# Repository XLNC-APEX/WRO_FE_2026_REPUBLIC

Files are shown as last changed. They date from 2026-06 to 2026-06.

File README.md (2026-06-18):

# 

 Welcome to the GitHub Repository of Team XLNC Apex from Kazakhstan, competing in the World Robot Olympiad Future Engineers 2026 category.

# Contents
- [The team](#the-team)
- [Challenge Overview](#challenge-overview)
- [Our Robot](#our-robot)
- [Mechanical systems](#mechanical-systems)
- [Electronic systems](#electronic-systems)
- [Software](#software)
- [Robot photos](#robot-photos)

## Directories structure
```shell
WRO_FE_2026_REGIONAL
├── code            # Our python code(uv project)
│   └── src         # Main code(open.py, obstacle.py)
│       └── tests   # Some code to test little things
├── images          # Images(for docs)
├── models          # Lego model, Pixy2 cam case
├── research        # Researches: obstacle, programming
├── t-photos        # Team photos
├── v-photos        # Vehicle Photos
└── README.md       # Main docs file
```

# The team

### Members

| Karabayev Darkhan | Abenov Sayan |
| --- | --- |
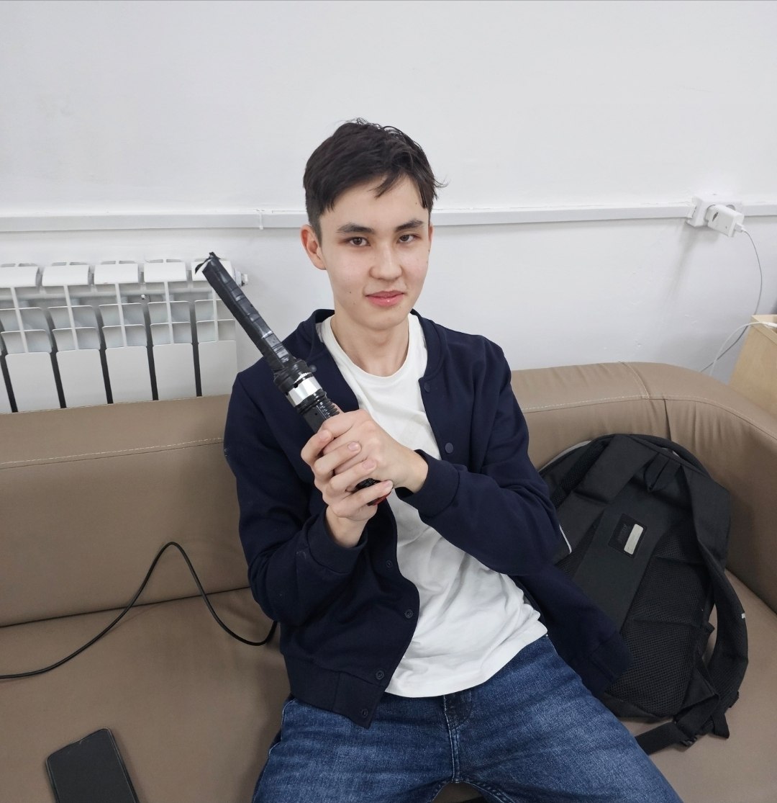
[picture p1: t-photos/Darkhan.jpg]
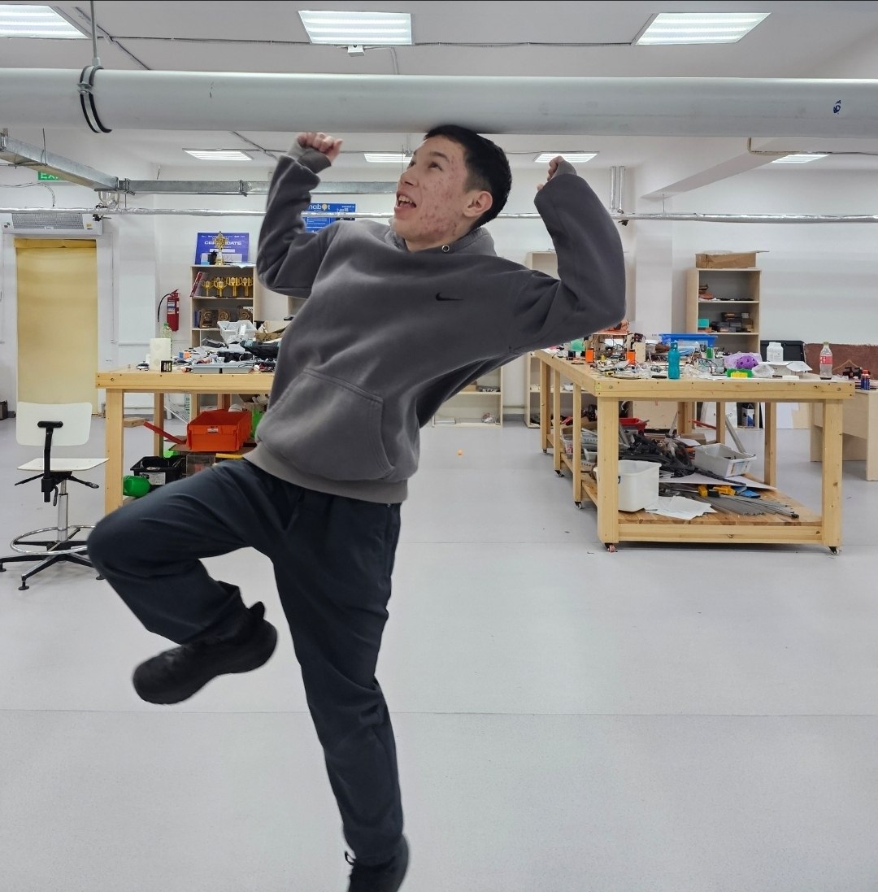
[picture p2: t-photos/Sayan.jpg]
|  |  |

# Challenge Overview

The **WRO Future Engineers** category requires building a **fully autonomous self-driving vehicle** that:

- Navigates a closed track without external control  
- Detects and avoids obstacles dynamically  
- Maintains stability and precision at speed  
- Adapts to uncertain and changing conditions  

Key engineering challenges:
- Real-time perception  
- Reducing sensor errors  
- Keeping right distance from walls  
- Reliability under competition constraints  

# System Architecture

Our robot is designed as a modular system consisting of three tightly integrated layers:

### 1. Perception Layer
- Vision-based detection using **Pixy2 camera**
- Object tracking and color signature recognition  
- Distance estimation using onboard sensors  

### 2. Control Layer
- Closed-loop control using **PID algorithms**  
- Steering and speed regulation  
- Real-time decision-making  

### 3. Execution Layer
- Motor actuation via LEGO EV3 platform  
- Precise movement and trajectory correction  

This layered approach allows us to isolate complexity and improve reliability.

# Our Robot

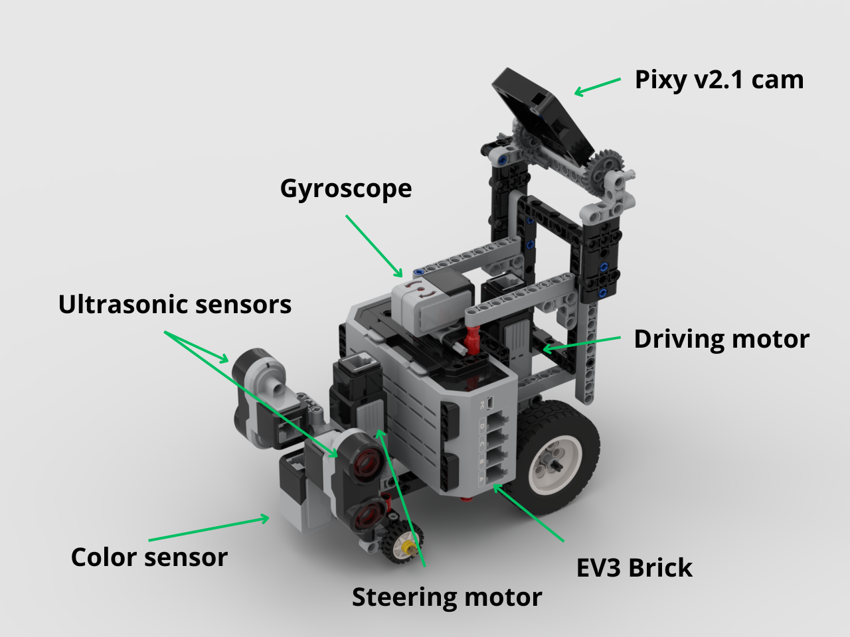
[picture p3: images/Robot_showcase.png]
Robot showcase


Our robot is a compact autonomous vehicle optimized for **speed, stability, and deterministic behavior**.

### Key Design Principles
- **Consistency over complexity**  
- **Low-latency decision making**  
- **Mechanical reliability first**  

### Capabilities
- Obstacle detection and avoidance  
- Smooth cornering with PID stabilization  
- Real-time trajectory correction  

# Mechanical Systems

The mechanical design is focused on achieving predictable and stable motion.

### Features
- Rigid and lightweight chassis  
- Optimized center of mass for high-speed turns  
- High-precision steering mechanism  
- Efficient drivetrain using LEGO components  

### Engineering Decisions
- Minimized mechanical play for better control accuracy  
- Balanced gear ratios for torque vs speed trade-off  
- Structural reinforcement for competition durability 

### Steering

### Geometry
We thought to use Ackerman's steering for more efficient turns. 
However, firstly we built this parallel steering.

incorrect_steering

Quickly noticed the issue and fixed it:

proper_steering

It works great, and since it meets our criteria, no Ackerman geometry is required.

| It is controlled by the medium ev3 motor. This motor has accurate encoder and after calibration at program start, it acts basically like a servo.| steering_motor |
| --- | --- |

### Rear-Wheel Drive(RWD)

We use differiential to properly drive while turning. It eliminates required otherwise wheels slippage, due to the fact that wheels travel arcs with different radii, thus, should rotate at different rates.
differential

It is powered by medium EV3 motor.

### Gyroscope

LEGO EV3 gyroscope is used to know robot orientation.

Problem: These gyroscopes drift frequently.

Reason: During gyroscope power on, it captures initial angular velocity. Also the error accumulates with time.

Solution: Power cycle the gyroscope. Pybricks added .calibrate() method to reboot ev3 gyro.

# Electronic Systems

Our robot is powered by the **LEGO EV3** platform with extended sensing capabilities.

### Core Components
- **LEGO EV3 Brick** — main controller  
- **Pixy2 Camera** — primary vision sensor  
- Motors with encoder feedback  
- Auxiliary sensors (distance, color, etc.)  

### Design Focus
- Reliable communication between modules  
- Low-latency sensor data processing  
- Stable power distribution  

When we started to prepare for WRO we had to choose the platform we are going to use.

We had a choice of completely custom platform or EV3 we already have.

Custom board requires us to choose components and order them, which can take up to a month of waiting. We have to design and 3d print parts.
Accounting for that, there probably at least a month to just assemble a first version of a robot. We wanted to start fast to spend more time programming.

The EV3 was the fastest to get started with.
EV3 robot assembly took approximately 1 day.(Later we added camera while programming).

[Assembly instructions for our robot are available.](xlnc_apex_instruction.pdf)

# Pixy 2.1 camera:

Photo of pixy 2.1 in our printed case on our robot

We had a part of the case, but not the front lid. That was an opportunity to learn FreeCAD and 3d printing! [Link to CAD](3d_models/pixy_holder/small_holder3.FCStd)

Pixy 2.1 front lid CAD

Camera is fixed on an axle and the viewing angle can be set using gears.

We set the optimal angle to fit as much field on screen and less noisy world

Camera view

# Software

The software stack is built using **Pybricks (MicroPython)** and follows a modular architecture.

### Core Modules
- **Steering Module**  
  - PD controller for gyroscope's angle
  - Tracking right steering angle 

- **Wall Avoidance Module**  
  - Finding the perpendicular to the outer wall
  - Proportional controller for distance from outer wall

- **Line Detection Module**  
  - Obstacle avoidance strategy  
  - State-based behavior system  

- **Obstacle Detection Module**  
  - Filtering unnecessary objects
  - The most optimal trajectory

### Coding platform:

After careful selection and [research](research/programming_environment_choice.md), for EV3, we chose an [experimental version of Pybricks](https://github.com/pybricks/pybricks-micropython/tree/master/bricks/ev3) with **significantly faster execution time** due to bare metal firmware and without the use of an SD card.

### Running the code

For uploading program to EV3 brick we use [pybricksdev](https://github.com/pybricks/pybricksdev). This package contains both command line tools and a library to call equivalent operations from within a Python script.

`pybricksdev` requires Python 3.10 or higher.

- For Windows, use the official Python installer or the Windows Store.
- For Mac, use the official Python installer or Homebrew (brew install python@3.12).
- For Linux, use the distro provided python3.12 or if not available, use a Python runtime version manager such as asdf or pyenv.

```shell
pybricksdev run usb code/src/open.py
```

### Pixy2 calibration

The Pixy2 camera is configured through the official PixyMon software. You need to connect the camera to your computer via the Micro-USB port to access the video and settings. By pressing and holding the white button, the camera enters teaching mode, and obstacle detection can be configured.

For more precise detection, signature ranges and camera brightness in settings need to be adjusted, and the Auto White Balance option should be switched off.

For more information, visit [Pixy Docs](https://docs.pixycam.com/wiki/doku.php?id=wiki:v2:teach_pixy_an_object_2).

### Open challenge:

For the open challenge, we chose a simple strategy of driving along the outer wall using a gyroscope and ultrasonic sensor. Turn and direction detection occur using a color sensor.

Firstly, the robot starts gyro calibration and angle resets. We reset the steering motor by running it until stalled to the left, to the right, and to the half. Then, a while loop starts until all 12 lines are passed. The car drives forward to the first line. The color sensor recognizes the color, whether it's orange or blue, and based on this, we can determine the direction (orange for clockwise and blue for counter-clockwise) and the right ultrasonic. Since the robot is driving along the outer wall, moving the internal walls won't bother the robot. The running loop operates at a > 50 Hz frequency; it's not much, but it's enough to successfully complete the task. We use a PD controller for the gyroscope and a proportional controller for wall detection. By reading the distance from the ultrasonic, we take into account the robot's rotation angle and find the perpendicular to the wall. To avoid reacting to the line twice per turn, we have a distance timeout, which is calculated using the rotation angle of the rear motor. Once the passed_lines variable is equal to 12 (which means all 3 laps are finished) the robot drives forward for a set period of time to land in its starting area and stops.

### Obstacle challenge:

The Obstacle Challenge is similar to the Open Challenge, with the exception of a Pixy2 camera correction as well as parking out.

#### Parking out
Robot is placed close to the farthest from moving direction parking wall. Then, the car determines the moving direction by the distance from side ultrasonic. 
The steering wheels rotate fully, car drives while turning, for approximately 800ms.

When the camera detects an obstacle, gyroscope and ultrasonic correction are disabled, and the robot follows the most optimal trajectory, which we've determined using point-based regression. As a result, the obstacle moves on the camera along an optimal nonlinear trajectory.

```python
#Code highlights
#code/src/ObstacleDetection.py
RED_CURVE = Curve2D(0.007155, -1.865848, 124.599494)
GREEN_CURVE = Curve2D(-0.007322, 1.880561, 187.050712)

#code/src/obstacle.py

obstacle_detection = ObstacleDetection(camera)

pixy_correction = obstacle_detection.get_correction()

steering.pid(pixy=pixy_correction, wall=wall_correction)
```

| **Green obstacle** | **Red obstacle** |
| --- | --- |
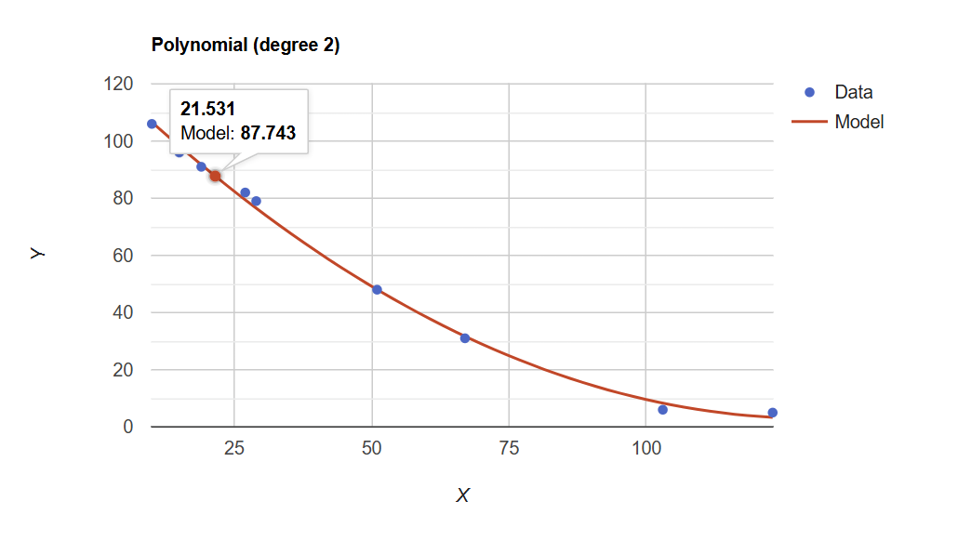
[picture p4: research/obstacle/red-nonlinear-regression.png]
Red obstacle trajectory
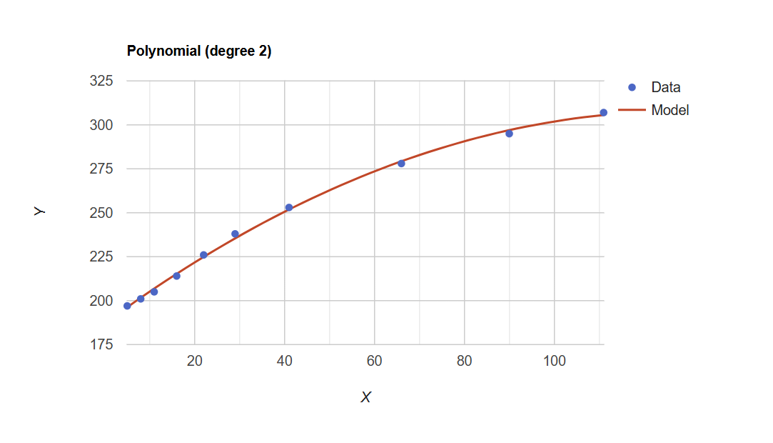
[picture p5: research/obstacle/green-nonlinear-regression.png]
Green obstacle trajectory
|  |  |

#### Obstacle filtering
Camera captures some out of field environment areas, as well as can be noisy and detect small blocks.

Filtering Blocks helps to reduce false positives. 

```python
#code/src/ObstacleDetection.py

def filter(block: Block) -> bool:
    if (block.height * block.width) > MIN_OBSTACLE_AREA:
        if crop_filter(block.x_center, block.y_center):
            return True
    return False

def crop_filter(x: int, y: int) -> bool:
    H_CROP = 10

    V_TOP_CROP = 35
    V_BOTTOM_CROP = 38
    if (x > H_CROP) and (x < (CAM_WIDTH - H_CROP)):
        if y > V_TOP_CROP:
            if y < (CAM_HEIGHT - V_BOTTOM_CROP):
                return True
    return False
```

We crop the view as well as discard too small blocks.

# Future plans & Problems

## Problems
 - Pixy2 is unstable, feature limited, power inefficient(heats up)

Plan: Try OpenMV H7 camera. It is programmable.

 - EV3 platform has limitations
    - low amount of ports
    - Limited programming ability
    - Big size and weight
    - Big slow motor

Plan: Build a robot with best available components like Pi Pico 2 microcontroller
([We already built it](https://github.com/XLNC-APEX/WRO_FE_2026_NATIONAL), but did not have time to program and document it)

 - Steering using EV3 medium motor requires finding extreme angles at initialization which takes ~ 1.5s

Plan: Use MG90S micro servo instead

# Robot photos

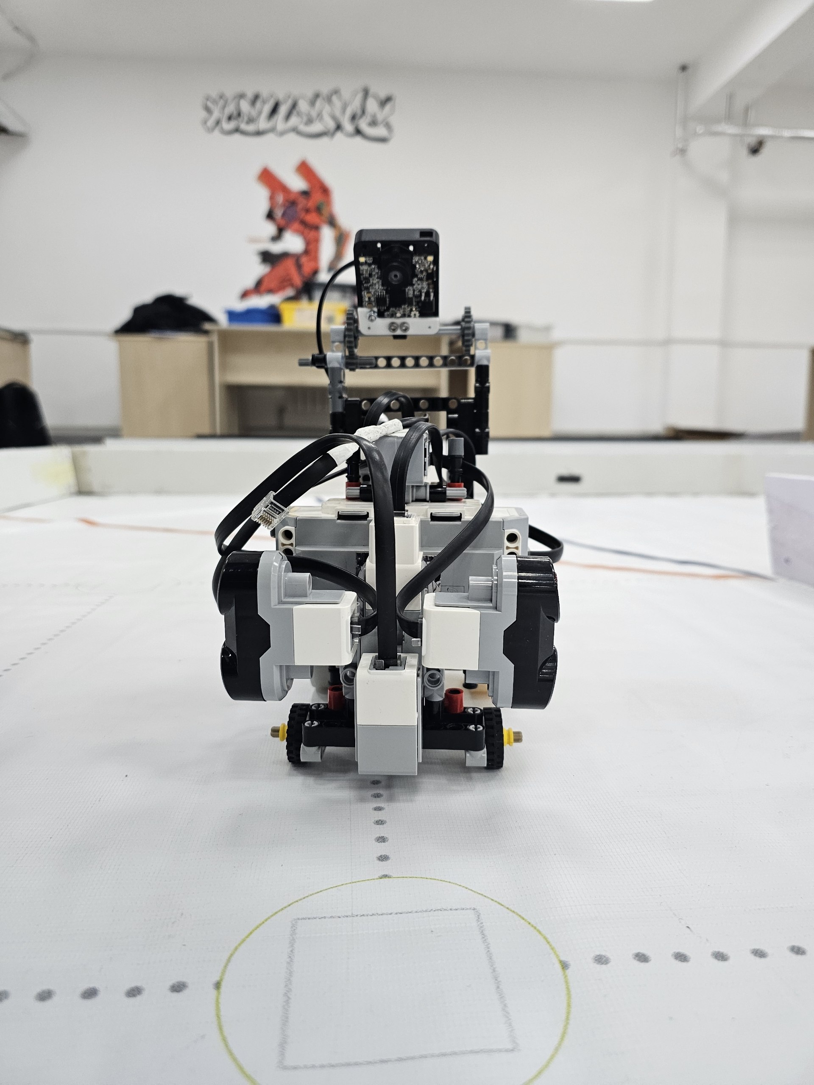
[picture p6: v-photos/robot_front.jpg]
Robot front
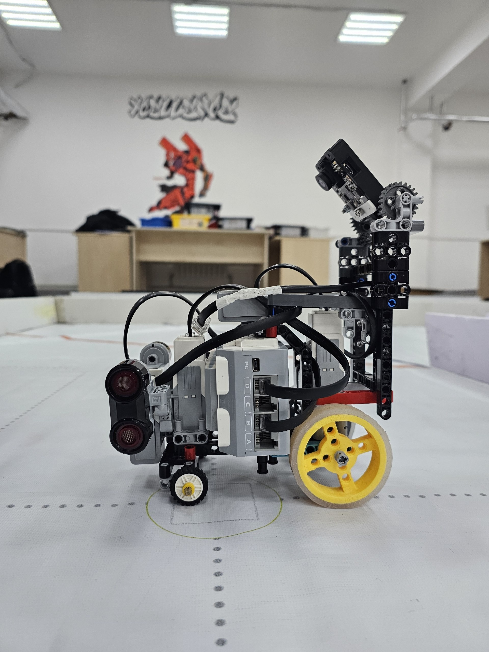
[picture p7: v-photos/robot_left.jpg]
Robot left
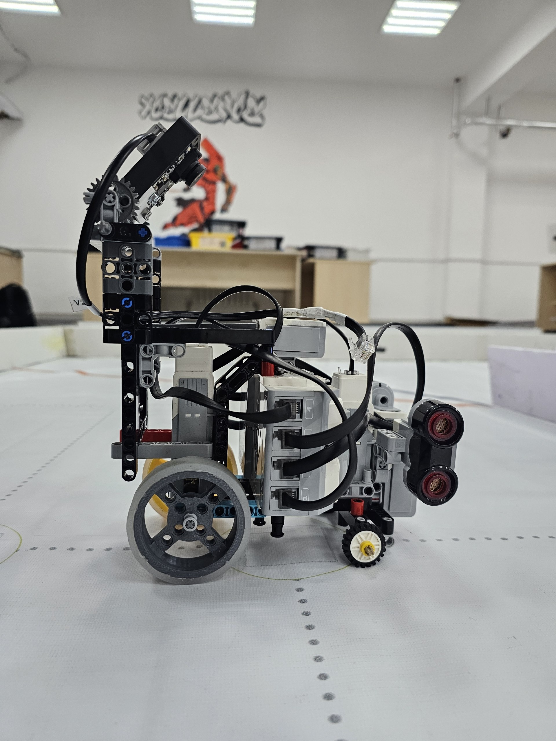
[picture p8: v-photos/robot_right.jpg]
Robot right
|  |  |  |
| --- | --- | --- |
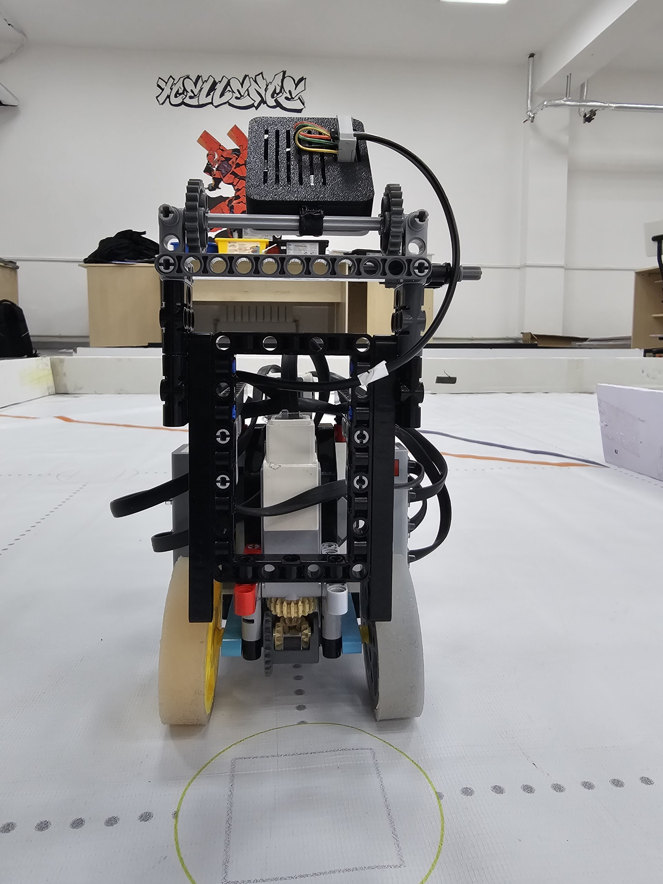
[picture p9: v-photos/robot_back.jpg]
Robot back
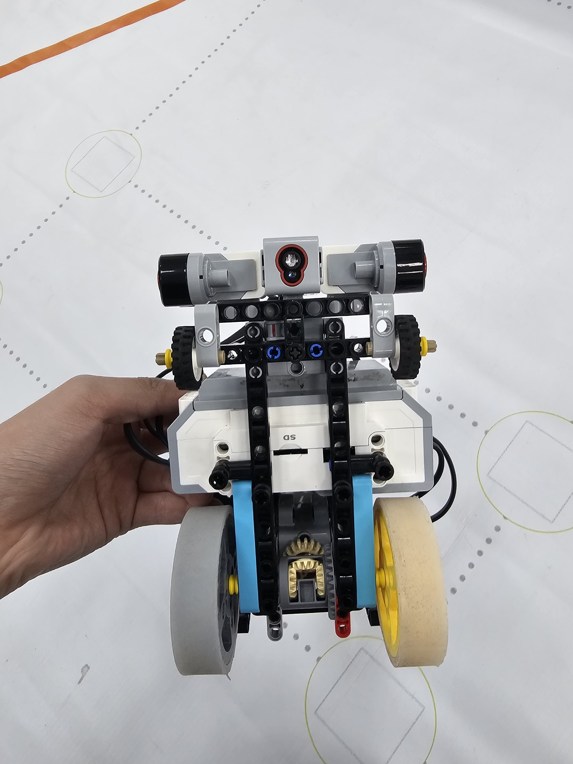
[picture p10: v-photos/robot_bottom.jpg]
Robot bottom
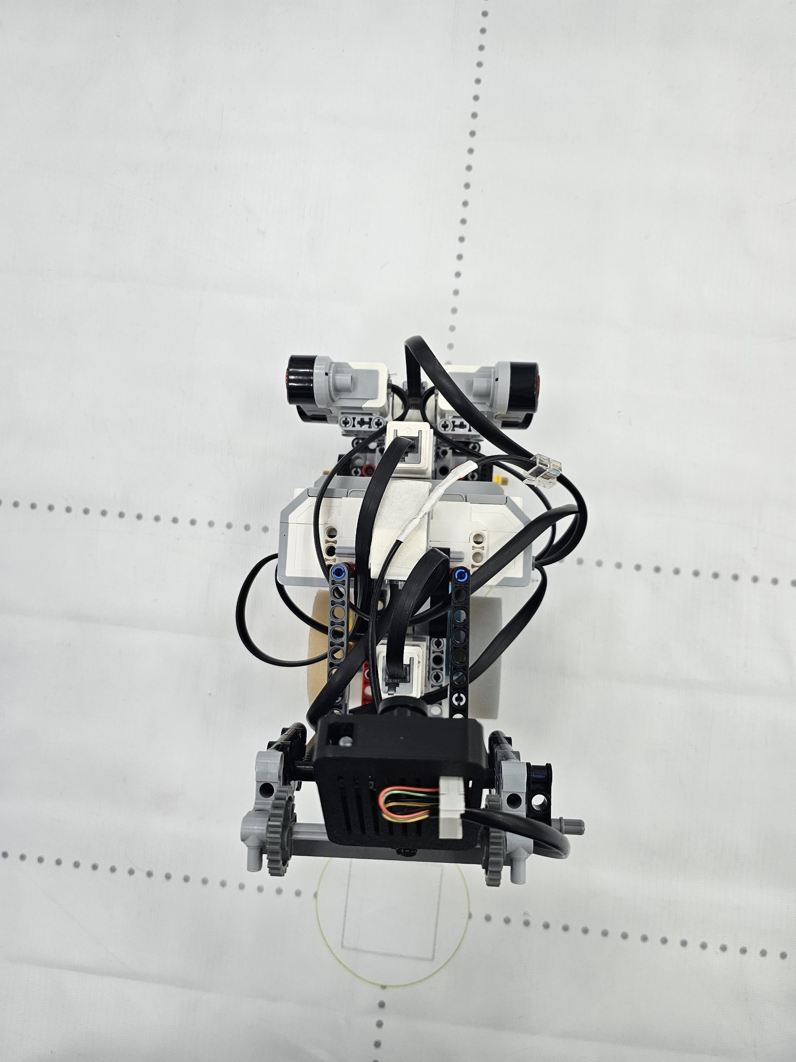
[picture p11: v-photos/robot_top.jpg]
Robot top
|  |  |  |

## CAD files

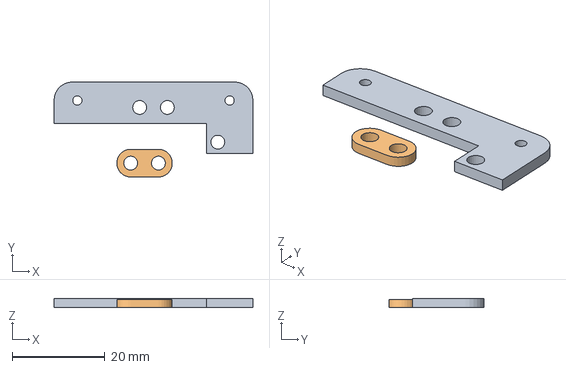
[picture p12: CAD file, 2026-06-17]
models/pixy_holder/small_holder3-main.3mf
43.0 x 20.5 x 2.00 mm

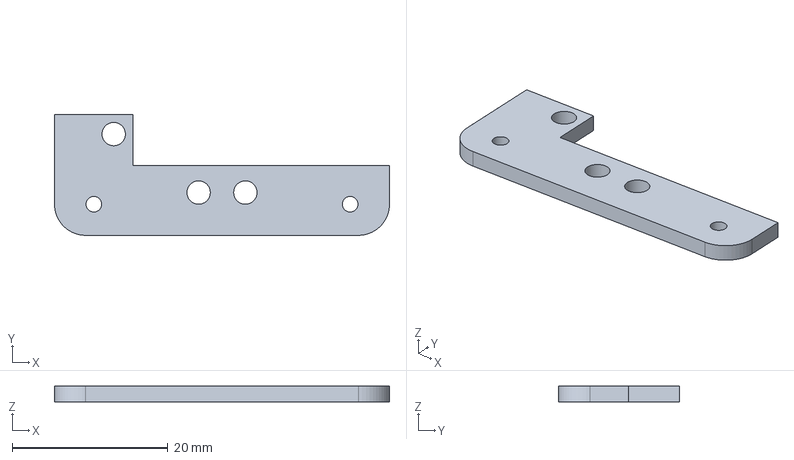
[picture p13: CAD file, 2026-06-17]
models/pixy_holder/small_holder3.FCStd
43.0 x 15.5 x 2.00 mm

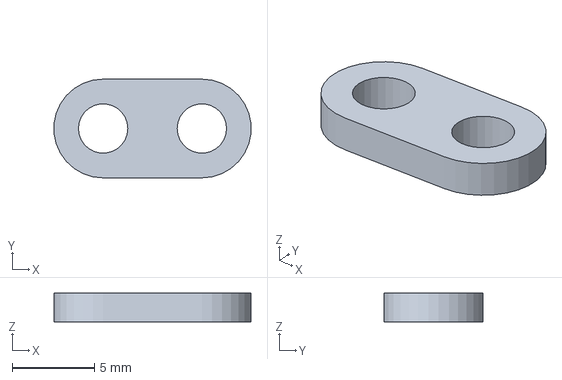
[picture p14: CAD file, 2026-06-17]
models/pixy_holder/small_holder3-spacer.3mf
12.0 x 6.00 x 1.75 mm

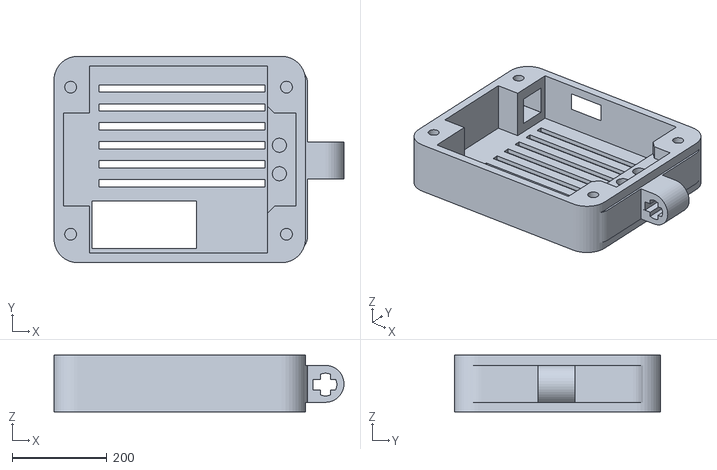
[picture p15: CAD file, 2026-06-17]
models/pixy_holder/pixy_2_case.stl
611.2 x 435.0 x 120.0

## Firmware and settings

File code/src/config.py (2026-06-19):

WHEEL_DIAMETER = 63  # mm

MAX_STEER = 35

CHECK_DISTANCE = 1300  # mm
START_CHECK_DISTANCE = 500  # mm

OBSTACLE_SAFE_DISTANCE_FROM_WALLS = 280  # mm
OPEN_SAFE_DISTANCE_FROM_WALLS = 100  # mm


OPEN_HIGH_SPEED = -1200
OPEN_LOW_SPEED = -1200

OBSTACLE_HIGH_SPEED = -900
OBSTACLE_LOW_SPEED = -700

MIN_OBSTACLE_AREA = 150

OPEN_GYRO_KP = 1.2

# OBSTACLE_COUNTER_GYRO_KP = 0.4
# OBSTACLE_COUNTER_GYRO_KP = 0.8

N_CONSEQ_COLORS = 8

# v1 (REGIONAL)
# OBS_PIXY_KP = 0.3
# OBSTACLE_GYRO_KP = 1.2
# OBS_ULTRASONIC_KP = 0.2

# v2
# OBS_PIXY_KP = 1.7
# OBSTACLE_GYRO_KP = 0.8
# OBS_ULTRASONIC_KP = 0.3

# v3
OBS_PIXY_KP = 1.9
OBSTACLE_GYRO_KP = 0.8
# OBS_ULTRASONIC_KP = 0.8
OBS_ULTRASONIC_KP = 0.7

ORANGE_COLOR = (31, 15, 15)
BLUE_COLOR = (7, 12, 27)

MIN_COLOR_DIST_SQUARED = 100

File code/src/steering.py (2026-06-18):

from config import MAX_STEER
from pybricks.ev3devices import GyroSensor, Motor
from pybricks.tools import StopWatch
from utils import constrain, normalize_angle

Ki = 0
Kd = 0.1


class Steering:
    def __init__(self, motor: Motor, gyro: GyroSensor):
        self.motor = motor
        self.gyro = gyro
        self.target_angle = 0
        self.integral_sum = 0
        self.last_error = 0
        self.timer = StopWatch()
        self.last_time = 0
        self.heading = 0

    def increase_target_angle(self, angle):
        self.target_angle += angle

    def reset_angles(self):
        self.motor.run_until_stalled(-500)
        self.motor.reset_angle(0)
        self.motor.run_until_stalled(500)
        angle = self.motor.angle()
        self.motor.run_angle(-500, angle // 2)

        self.motor.reset_angle(0)
        self.gyro.reset_angle(0)

    def pid(self, Kp=0.8, pixy=0.0, wall=0.0):
        current_time = self.timer.time() / 1000
        dt = current_time - self.last_time
        self.last_time = current_time
        dt = max(dt, 0.01)

        self.heading = self.gyro.angle()

        error = self.target_angle - self.heading

        if abs(error) < 2:
            error = 0

        derivative = (error - self.last_error) / dt
        self.integral_sum += error * dt

        self.integral_sum = constrain(self.integral_sum, -100, 100)  # TODO: CHANGE IT

        out = (error * Kp) + (self.integral_sum * Ki) + (derivative * Kd)

        out += wall
        if abs(pixy) > 0:
            out = pixy

        out = constrain(out, -MAX_STEER, MAX_STEER)

        self.motor.track_target(out)

        self.last_error = error

        return out

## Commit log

2026-06-17 add pixy2 case model
    [pixy_2_case.stl]
2026-06-17 renamed models folder
    [pixy_2_case.stl, small_holder3-main.3mf, small_holder3-spacer.3mf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]
2026-06-17 add robot_showcase and pixy case to instruction
2026-06-18 [Docs] add code examples to obstacle pixy2 correction, filtering
2026-06-18 add pixy calibration to readme
2026-06-18 divide open and obstacle gyro kp
2026-06-18 temp commit need to fix
    [line_detection.py, obstacle.py]
2026-06-18 some refactoring and fixed bugs
    [obstacle.py]
2026-06-18 [Code] add color filter, rgb scaling
2026-06-18 add reset angle and ultrasonic rotation
    [obstacle.py, wall_avoidance.py]
2026-06-18 refactored obstacle, added ultrasonic rotation
2026-06-19 color detection changed to vectors and some fixes
    [color_test.py, config.py, line_detection.py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]
